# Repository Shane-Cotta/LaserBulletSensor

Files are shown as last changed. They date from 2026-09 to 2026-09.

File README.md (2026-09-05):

# Laser Bullet Sensor

A DIY **laser bullet presence / orientation sensor** for **Mark 7 Autodrive** progressive presses (Apex 10, Evolution, and other Autodrive-equipped machines). A background-suppression laser photoelectric sensor sits on a 3D-printed bracket and looks across the shell plate at the bullet on the case at the seating station. If there's no bullet — or it's sitting wrong — the sensor flips its output and the Autodrive stops the press with an **ERROR** on the tablet before it indexes to the next station.

It's a DIY alternative to a commercial bullet sensor, built from off-the-shelf parts and **four 3D-printed pieces**:

- **Laser Bullet Sensor Bracket** — bolts to the press body and clamps the linear rod.
- **Laser Bullet Sensor Linear Rod** — the post the sensor mounts to; slides and rotates in the bracket clamp for height and aim.
- **PCB Housing (Top + Bottom)** — the box for the **PNP Sensor Power Supply PCB**, with cutouts for the INPUT / OUTPUT plugs and the PNP/NPN switch.

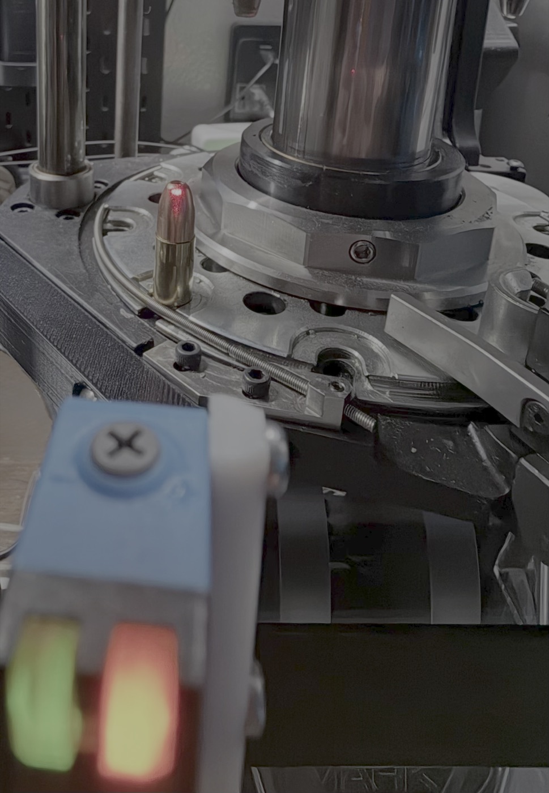
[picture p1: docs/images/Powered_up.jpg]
Laser Bullet Sensor running on the press


> ⚠️ **This is a hobbyist project shared as-is, with no warranty.** A DIY sensor is a backstop, not a substitute for safe reloading practice and visual inspection. Test thoroughly with dummy/empty cases before live loading, and follow Mark 7's guidance for wiring anything into your press. You are responsible for your own machine and your own safety.

> 👁️ **Laser safety.** The sensor emits a visible red laser. Don't stare into it, don't aim it at eye level while you're setting it up, and do your alignment with the press stopped.

---

## Video guide

Four short videos walk through the whole thing. They're linked again in the sections they cover. Playlist: [tinyurl.com/BulletSensor](https://tinyurl.com/BulletSensor)

| | |
|---|---|
| Unboxing and initial setup overview (https://youtu.be/-Qg1wYBSL-w)<br>**1. Unboxing and initial setup overview** | Mounting options on the Mark 7 press (https://youtu.be/lcT0eZi-Rhc)<br>**2. Mounting options on the Mark 7 press** |
| Testing the Sensor (https://youtu.be/pjvrqv03DK4)<br>**3. Testing the Sensor** | Adjusting Sensor detection distance (https://youtu.be/uPvdZVN8Cnk)<br>**4. Adjusting Sensor detection distance** |

---

## Ways to build it

This is documented to be built yourself. Every commodity component is off-the-shelf and linked in the [bill of materials](#bill-of-materials), all four printed parts are in [`hardware/`](hardware/) as STL files, and the wiring is spelled out end to end. The one piece you get from me is the **PNP Sensor Power Supply PCB** — the boost/isolation board that sits between the press and the sensor — sold assembled because it's the part that's genuinely fiddly to source and build on your own.

If you'd rather skip the printing and crimping altogether, the whole thing is also available built and tested. Two ways to go:

| Level | You supply | You buy ready-made |
|---|---|---|
| **DIY** | The commodity parts (sensor, cables, terminal plugs, screws) ordered from the BOM links, all four pieces printed on your own machine, the wiring and tuning | The [PNP Sensor Power Supply PCB](https://go.khcprecision.com/PNP_PCB), assembled |
| **Assembled** | Bolting it to your press and dialing in the distance | A complete, built and tested sensor — what you see in the [unboxing video](https://youtu.be/-Qg1wYBSL-w) |

**Store:** the parts for this build have live **Add to cart** buttons right under this design on [khcprecision.com/diy](https://khcprecision.com/diy); individual parts are also in the [**Parts** section](https://khcprecision.com/store#parts) of the store. Inventory shown on the site is live and I keep it stocked as best I can; orders generally ship within **2–4 business days**.

---

## How it works

The **NBG-JS30P** is a *background-suppression* diffuse photoelectric sensor: it fires a visible red laser at the target and uses triangulation to decide whether something is inside its set distance window (adjustable from about **20 to 300 mm**), largely regardless of the object's colour. Aimed across the shell plate at the seating station, a bullet sitting on the case mouth falls inside the window; an empty case mouth, a missing bullet, or a bullet lying sideways doesn't. The sensor has a **PNP** (sourcing) output — when it sees the bullet, its black output wire is pulled up to the sensor supply voltage.

The sensor wants **10–30 VDC** and the Autodrive sensor port only offers **5 V**, so there's a small board in between. The **PNP Sensor Power Supply PCB** takes the Autodrive's 5 V on its **INPUT** plug, boosts it to **12 V** for the sensor on its **OUTPUT** plug, and passes the sensor's PNP output back through an **opto-isolator** to the Autodrive's SIG line — so the sensor side and the press electronics never share a direct electrical path. The board has a small slide switch, **SW1**, that selects **NPN** or **PNP** sensor logic. **This build uses a PNP sensor, so SW1 must be on PNP before you power it up.**

On the press side, the board plugs into the Autodrive's **Bullet Sense** port, and you enable **Bullet Sense** on the tablet. From then on the Autodrive treats it like the factory sensor: a fault stops the press and throws an error.

---

## Bill of materials

Part links go to **Amazon** for commodity components and to **[KHC Precision](https://khcprecision.com/diy)** for the PCB — see [Ways to build it](#ways-to-build-it). Source them wherever you like; nothing is proprietary.

| # | Part | Qty | Notes |
|---|---|-----|---|
| 1 | **PNP Sensor Power Supply PCB** (assembled) — [link](https://go.khcprecision.com/PNP_PCB) *(KHC Precision)* | 1 | 5 V in → 12 V out, opto-isolated signal, SW1 NPN/PNP switch. Fits the PCB Housing in `hardware/` |
| 2 | **NBG-JS30P** background-suppression laser photoelectric sensor — [link](https://www.amazon.com/dp/B0GX4SXS33) | 1 | 20–300 mm, 10–30 VDC. ⚠️ **Must be the PNP "JS30P" version** — the NPN "JS30N" will not work with this wiring. Comes with 2 mounting screws and 2 nuts; you'll use all of them |
| 3 | 3-pin **3.81 mm right-angle pluggable screw terminal block** — [link](https://www.amazon.com/dp/B0CN8ZY184) | 2 (sold as a pack of 20) | One pushes into the PCB's **INPUT** side, one into the **OUTPUT** side |
| 4 | **ATX 4-pin CPU extension cable** — [link](https://www.amazon.com/dp/B01DV1Z36A) | 1 (sold as a 2-pack) | Plugs into the Autodrive's Bullet Sense port; the other end gets cut off and landed on the INPUT plug. See [Wiring](#2-wiring) |
| 5 | **1/4-20 × 3/4" button head socket cap screws** — [link](https://www.amazon.com/dp/B07TJN6L2J) | 2 (sold as a pack of 25) | Mount the bracket to the press body |
| 6 | **M3 × 20 screw** | 1 | With **one of the two nuts included with the sensor** — provides adjustable clamp tension on the bracket where it grips the linear rod |
| 7 | Sensor's **included screws** (2) | — | Mount the sensor to the linear rod |
| 8 | **Laser Bullet Sensor Bracket** (3D printed) | 1 | `hardware/Laser Bullet Sensor Bracket.stl` |
| 9 | **Laser Bullet Sensor Linear Rod** (3D printed) | 1 | `hardware/Laser Bullet Sensor Linear Rod.stl` |
| 10 | **PCB Housing Top + Bottom** (3D printed) | 1 each | `hardware/PCB_Housing_Top.stl`, `hardware/PCB_Housing_Bottom.stl` |

> The components are third-party products sold under their own terms. This project only covers the printed parts, wiring, and documentation.

**What's in the kit** (the Assembled option): the sensor with its cable already landed on an OUTPUT plug, the printed bracket and rod, the sensor's screws and nut, the PCB in its housing, and a pre-made Autodrive cable (Molex on one end, INPUT plug on the other). The [unboxing video](https://youtu.be/-Qg1wYBSL-w) goes through all of it.

---

## 1. Print the parts

All four parts are in [`hardware/`](hardware/) as STL files, modeled in millimetres:

- `Laser Bullet Sensor Bracket.stl` — the arm that bolts to the press, with a split clamp at the end for the rod.
- `Laser Bullet Sensor Linear Rod.stl` — the post the sensor screws to.
- `PCB_Housing_Top.stl` / `PCB_Housing_Bottom.stl` — the box for the power supply PCB.

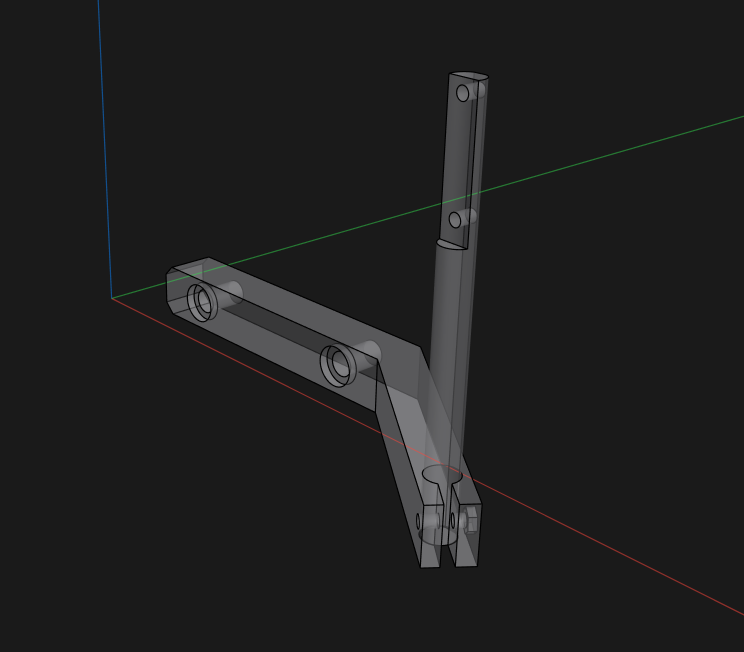
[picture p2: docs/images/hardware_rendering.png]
Bracket and linear rod


- **Material:** PETG or ABS/ASA recommended for stiffness and proximity to the press; PLA works for bench testing.
- **Suggested settings:** 0.2 mm layers, 5 Walls, 20–30% infill. The bracket and rod carry the sensor's weight and get clamped, so don't skimp on perimeters.
- Print the bracket flat on its long face and the rod on its side so the clamp bore and the sensor holes come out round; add supports only if your orientation needs them.
- Test-fit the rod in the bracket clamp, the sensor screws in the rod, and the PCB in the housing before final assembly. Tune your slicer's hole/horizontal-expansion compensation if anything is tight.

---

## 2. Wiring

Wiring diagram

**Signal chain:** Autodrive Bullet Sense port (5 V) → **INPUT** plug → PNP Sensor Power Supply PCB (boost to 12 V) → **OUTPUT** plug → NBG-JS30P → laser → bullet; NBG-JS30P PNP output → PCB (opto-isolator) → Autodrive SIG.

Six wires total, three on each plug. The lid of the PCB housing is your reference for which side is which:

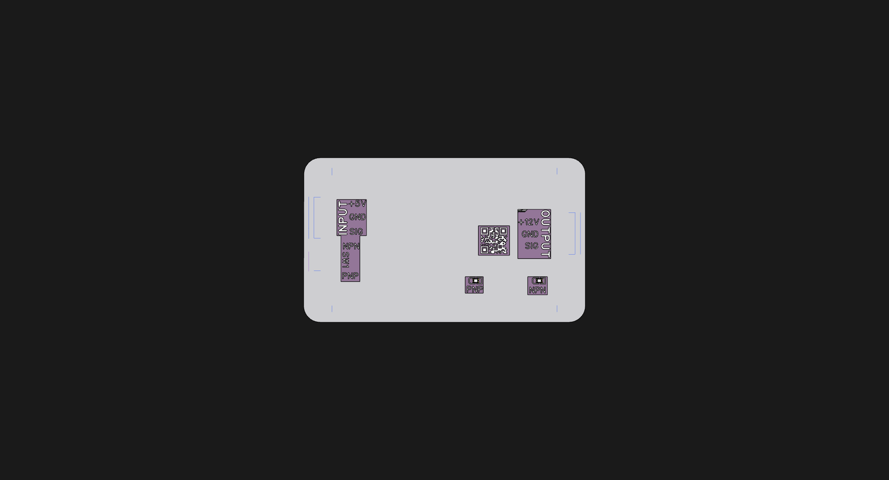
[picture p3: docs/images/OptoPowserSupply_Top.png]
PCB housing lid — INPUT, SW1, OUTPUT labels


| INPUT side | OUTPUT side |
|---|---|
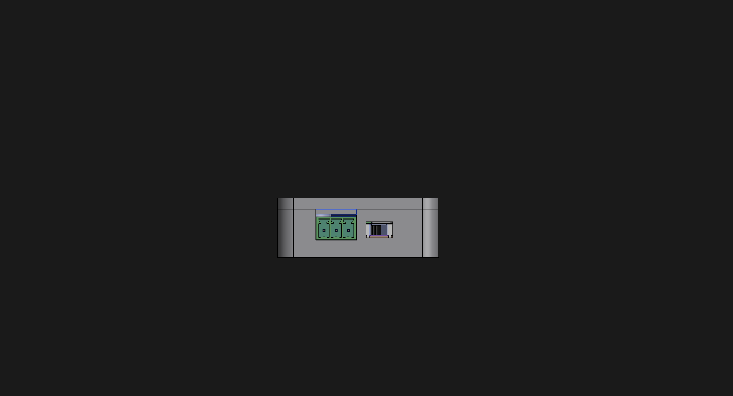
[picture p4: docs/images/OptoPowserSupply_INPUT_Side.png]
INPUT side
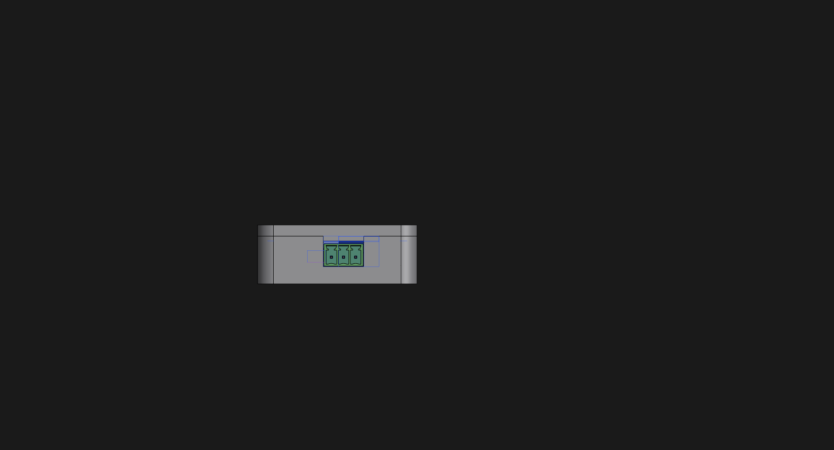
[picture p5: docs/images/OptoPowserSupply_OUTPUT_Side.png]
OUTPUT side
|  |  |

### Sensor → OUTPUT plug

Land the sensor's cable on one of the 3.81 mm plugs and push it into the **OUTPUT** side. Standard sensor colours:

| OUTPUT terminal | Sensor wire |
|---|---|
| **+12V** | Brown |
| **GND** | Blue |
| **SIG** | Black (PNP output) |

If your sensor has a fourth (white) wire, leave it insulated and unconnected.

### Autodrive → INPUT plug

The Autodrive's Bullet Sense port is a 4-pin Molex (Mini-Fit Jr style, same as an ATX CPU power plug). You have two ways to get from there to the INPUT plug:

- **Easy:** take the [ATX 4-pin CPU extension cable](https://www.amazon.com/dp/B01DV1Z36A), plug its Molex end into the Bullet Sense port, and **cut the other connector off**. Land three of the four wires on a 3.81 mm plug and push it into the **INPUT** side.
- **DIY:** crimp your own 4-pin Mini-Fit Jr plug and pigtail.

Either way, this is the pinout of the Autodrive port, looking into it with the **latch up**:

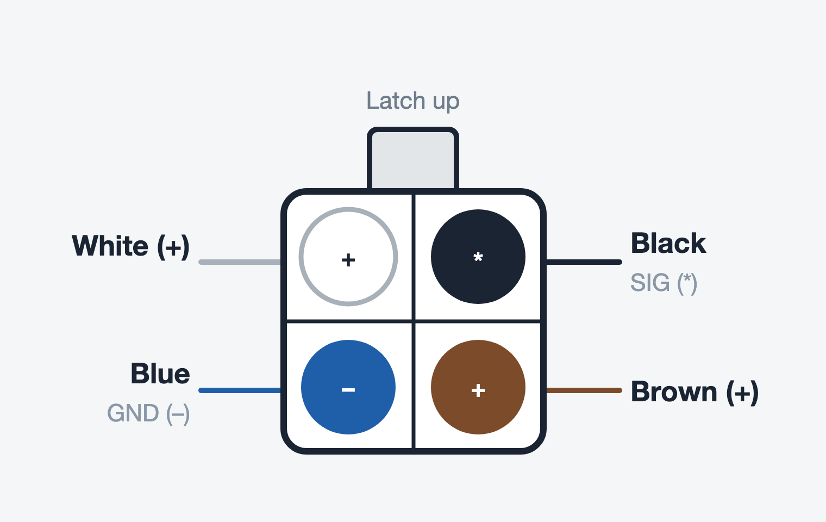
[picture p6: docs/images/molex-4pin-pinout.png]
Autodrive Bullet Sense port pinout


| Port position (latch up) | INPUT terminal |
|---|---|
| **Brown (+)** — bottom right | **+5V** |
| **Blue (−)** — bottom left | **GND** |
| **Black (\*)** — top right | **SIG** |
| **White (+)** — top left | not used |

> ⚠️ **Go by pin position, not wire colour.** The ATX extension cable's wires are yellow and black, and they do **not** line up with the functions above — a yellow wire may well be your GND. Identify each wire by which cavity it sits in on the Molex end, then land it accordingly.

> ⚠️ **Confirm the +5 V pin with a meter before you land it.** Two positions on the port are marked (+). Power the Autodrive, probe the port, and make sure the pin you're using for **+5V** actually reads +5 V relative to the GND pin. Putting the wrong thing on the INPUT +5V terminal can damage the board.

### Set SW1 to PNP

Before applying power, set **SW1** on the PCB to **PNP**. The housing lid shows the two switch positions; the switch is reachable through the wall on the INPUT side. The board ships on whichever position it was last tested at, so check it every time.

> ⚠️ INPUT and OUTPUT plugs are not interchangeable. The INPUT side takes 5 V in from the press; the OUTPUT side puts 12 V out to the sensor. Swapping them will not power the sensor and can damage the board.

---

## 3. Assembly

**Sensor and rod:**
1. Mount the **NBG-JS30P** to the **Linear Rod** with the sensor's two included screws through the rod's mounting holes. Snug, not crushed — the sensor body is plastic.
2. Slide the rod into the **Bracket**'s split clamp. Fit the **M3 × 20** screw across the clamp with one of the sensor's nuts on the far side. This is your tension adjustment: loose enough to slide and rotate the rod, tight enough that it stays put once you've aimed it.

**Power supply PCB:**
3. Seat the PCB in **PCB_Housing_Bottom** with the INPUT and OUTPUT sockets facing their cutouts and SW1 lined up with its opening.
4. Set **SW1 to PNP** (see [Wiring](#set-sw1-to-pnp)).
5. Fit **PCB_Housing_Top**.

**Cables:**
6. Push the sensor's plug into **OUTPUT** and the Autodrive plug into **INPUT**, per the [wiring tables](#2-wiring). Both plugs are keyed to their sockets; don't force them.
7. Give both cables a little slack and route them clear of the shell plate, the ram, and the case/bullet feeder.

---

## 4. Mount to the Mark 7

Mounting options on the Mark 7 press (https://youtu.be/lcT0eZi-Rhc)

1. Bolt the **Bracket** to the press body with the two **1/4-20 × 3/4" button head screws** through the bracket's two mounting holes. The [mounting video](https://youtu.be/lcT0eZi-Rhc) shows the positions that work and the orientation for each.
2. Loosen the clamp screw, then **slide the rod for height and rotate it for aim** so the laser dot lands squarely on the bullet's ogive at the seating station — the photo at the top of this page is the target. The bullet should be the closest thing in the beam's path.
3. Tighten the clamp screw until the rod holds. Cycle the press by hand and make sure nothing — shell plate, ram, feeder, case — comes near the sensor or its cable.
4. Set the PCB housing somewhere out of the way (the bench beside the press is fine) with the cables clear of the machine.

> Consistency is everything. The sensor is doing a distance measurement, so a bracket that flexes or a rod that creeps will give you random errors. If it moves, tighten it.

---

## 5. Adjust the detection distance

Adjusting Sensor detection distance (https://youtu.be/uPvdZVN8Cnk)

The NBG-JS30P has a **distance adjustment screw** on top (under the small dial). Turning it sets how far out the sensor will accept a target. Two LEDs on the sensor tell you what it sees: **green = powered**, **orange = output on (target detected)**.

1. Power the press so the sensor is live (green LED). Put a case with a **correctly seated bullet** at the seating station.
2. Turn the adjustment screw until the **orange LED comes on** — the bullet is now inside the window.
3. Remove the bullet (or swap in an empty case). The orange LED should go **off**. If it stays on, the window reaches past the bullet to something behind it — back the adjustment off until it clears.
4. Put the bullet back and confirm it lights again. You want some margin on both sides, so aim for the middle of the range where it reliably switches, not the edge.
5. Try a sideways or upside-down bullet, and a case with no bullet. Each should drop the orange LED.

The [distance video](https://youtu.be/uPvdZVN8Cnk) shows the whole adjustment in under two minutes.

---

## 6. Connect to the Autodrive and test

Testing the Sensor (https://youtu.be/pjvrqv03DK4)

1. Plug the Molex end of the Autodrive cable into the **Bullet Sense** port on the Autodrive.
2. On the tablet, **enable Bullet Sense**. The Autodrive now watches the sensor on every stroke.
3. Run the press with dummy or empty cases and **no bullet** at the seating station. The Autodrive should stop and show **ERROR**, exactly like the [testing video](https://youtu.be/pjvrqv03DK4).
4. Clear the error, add a bullet, and run again — it should cycle normally.
5. Only once it passes both tests should you go back to live loading.

You can disable Bullet Sense from the tablet when you're running the press without seating bullets (brass processing, sizing-only passes, and so on).

---

## Troubleshooting

- **No LEDs on the sensor:** the sensor isn't getting 12 V. Check that the sensor plug is in **OUTPUT** and the Autodrive plug is in **INPUT** (not swapped), that the Autodrive is powered, and — with a meter — that the wire you landed on INPUT **+5V** is really +5 V.
- **Green LED on, orange never comes on:** the bullet is outside the window. Aim the laser dot at the bullet and re-do the [distance adjustment](#5-adjust-the-detection-distance). Also confirm you have the **PNP (JS30P)** sensor.
- **Orange LED on all the time:** the window is too long and the sensor is seeing the shell plate, the ram, or the far side of the press. Shorten the distance, or re-aim so nothing sits behind the bullet inside the window.
- **Sensor switches correctly but the press never errors:** SW1 is probably on **NPN** — flip it to PNP. Otherwise check that Bullet Sense is **enabled** on the tablet and the cable is in the **Bullet Sense** port.
- **Press errors at random:** the bracket or rod is moving, or the bullet is right at the edge of the window. Tighten the clamp and the press screws; set the distance with more margin.
- **Trips on some bullets and not others:** long and short bullets put the ogive at different heights. Re-aim the beam for the bullet you're loading, or aim lower on the shank where every bullet is the same.

---

## Support the Project

If this project helped you on your reloading journey, saved you some troubleshooting time, or inspired your own DIY build, and you'd like to support continued development and experimentation, you can do so here:

[Support the Project](https://donate.stripe.com/9B69AT9jK94z3j71312Ji00)

Buying a part or a built sensor from [KHC Precision](https://khcprecision.com/diy) supports it just as directly.

## License

This project's original work — including the custom 3D-printable bracket, rod, and housing designs, the wiring diagram, photos, assembly instructions, and documentation — is licensed under the:

**Creative Commons Attribution-NonCommercial-ShareAlike 4.0 International License (CC BY-NC-SA 4.0)**

You are free to:
- **Share** — copy and redistribute the material in any medium or format
- **Adapt** — remix, transform, and build upon the material

Under the following terms:
- **Attribution** — You must give appropriate credit and indicate if changes were made.
- **NonCommercial** — You may not use the material for commercial purposes.
- **ShareAlike** — If you remix, transform, and build upon the material, you must distribute your contributions under the same license.
- **No additional restrictions** — You may not apply legal terms or technological measures that legally restrict others from doing anything the license permits.

Full license text:  
https://creativecommons.org/licenses/by-nc-sa/4.0/

See [LICENSE.md](LICENSE.md) for the full notice.

### Scope of this license

This license applies only to the original project materials contained in this repository, including:
- 3D-printable designs (bracket, linear rod, PCB housing)
- STL/CAD files
- Wiring diagrams
- Documentation and photos
- Original assembly instructions

Third-party hardware components, manufacturer manuals, trademarks, firmware, and product names remain the property of their respective owners and are covered by their own licenses and terms.

### Commercial use

Commercial manufacturing, resale, kit sales, paid assembly services, or redistribution of modified versions for commercial purposes are not permitted without separate written permission from the project author.

### Commercial licensing

If you are interested in manufacturing, selling kits, offering assembled units, bundling this project into commercial products, or otherwise using this work commercially, please contact the project author to discuss licensing arrangements or collaboration opportunities.

### Disclaimer

This project is provided "as is", without warranty of any kind, express or implied. Reloading ammunition and modifying automated loading equipment can be dangerous. You are solely responsible for verifying safe operation, proper wiring, and safe reloading practices before use.

Always test thoroughly with dummy or inert components before live operation.

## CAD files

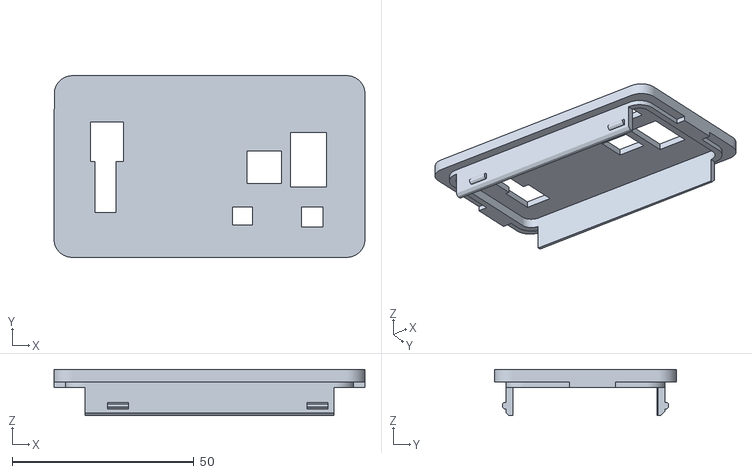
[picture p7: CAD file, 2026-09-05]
hardware/PCB_Housing_Top.stl
85.7 x 50.0 x 12.8

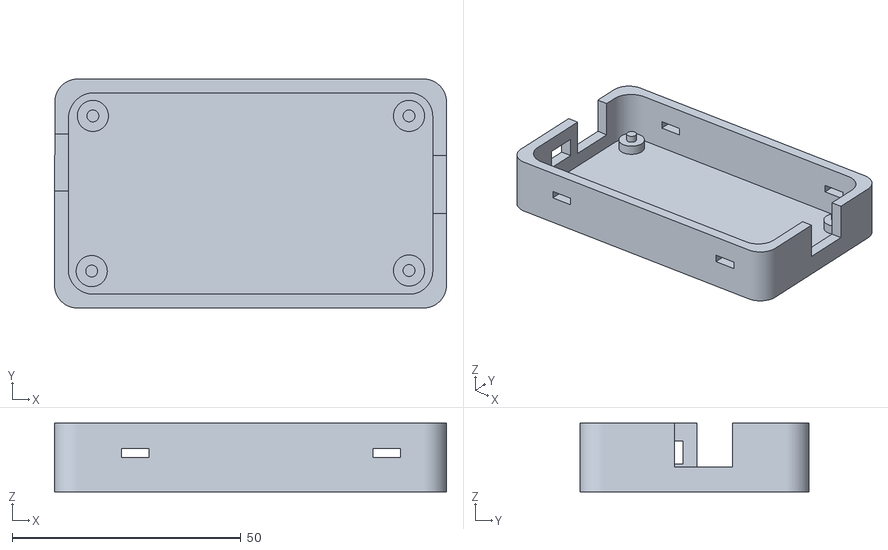
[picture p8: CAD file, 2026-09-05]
hardware/PCB_Housing_Bottom.stl
85.7 x 50.0 x 15.0

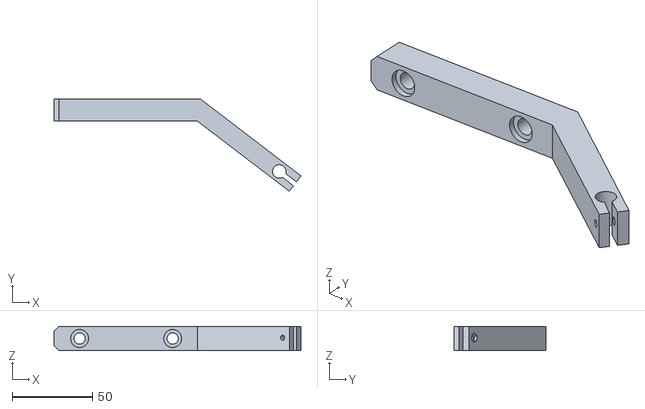
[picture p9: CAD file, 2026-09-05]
hardware/Laser Bullet Sensor Bracket.stl
154.0 x 57.6 x 15.0

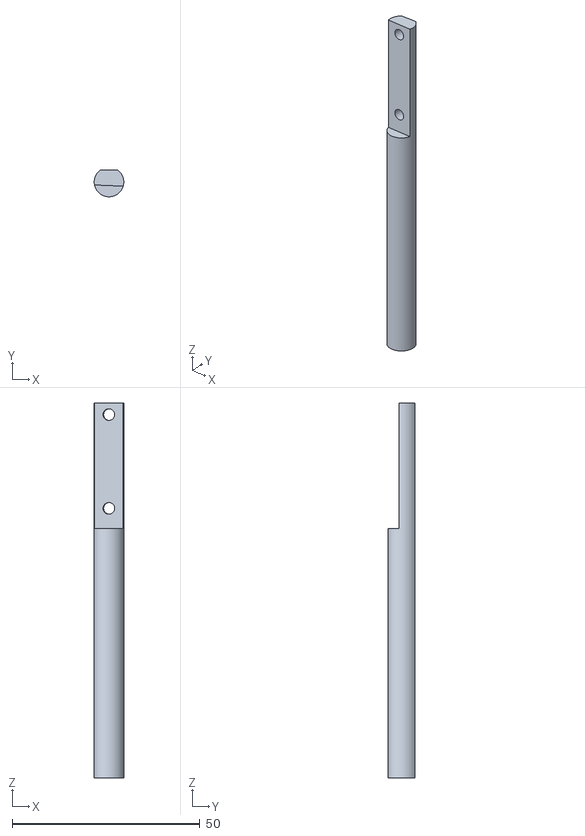
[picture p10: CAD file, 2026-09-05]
hardware/Laser Bullet Sensor Linear Rod.stl
7.90 x 7.11 x 100.0

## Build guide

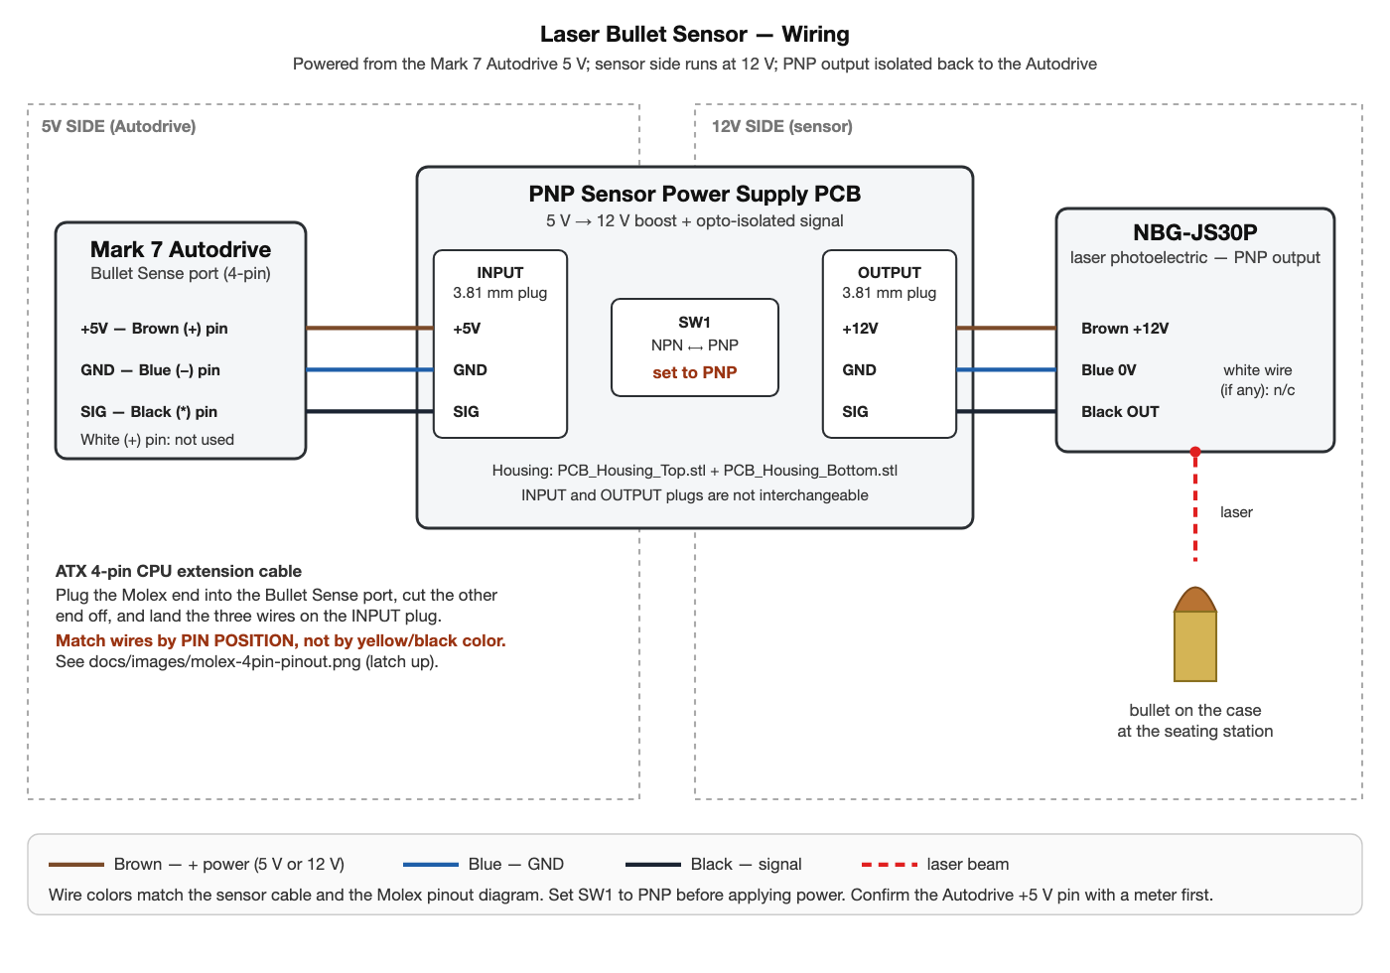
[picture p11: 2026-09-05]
docs/wiring-diagram.png

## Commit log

2026-09-05 Add wiring diagram for Laser Bullet Sensor in SVG format
    - Created a detailed SVG diagram illustrating the wiring setup for the Laser Bullet Sensor.
    - Included sections for the 5V side (Autodrive) and 12V side (sensor), along with component labels and notes.
    - Documented connections for the Mark 7 Autodrive, PNP Sensor Power Supply PCB, and NBG-JS30P sensor.
    - Added a legend for power, ground, signal, and laser beam indicators.
2026-09-05 Update wiring diagram and README with improved settings and dimensions
2026-09-05 Update README to clarify DIY build options and availability of assembled PCB
